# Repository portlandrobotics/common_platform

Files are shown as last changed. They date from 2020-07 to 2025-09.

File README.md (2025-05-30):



<!-- PROJECT SHIELDS -->
<!--
*** I'm using markdown "reference style" links for readability.
*** Reference links are enclosed in brackets [ ] instead of parentheses ( ).
*** See the bottom of this document for the declaration of the reference variables
*** for contributors-url, forks-url, etc. This is an optional, concise syntax you may use.
*** https://www.markdownguide.org/basic-syntax/#reference-style-links
-->
[][contributors-url]
[][forks-url]
[][stars-url]
[][issues-url]
[][license-url]

<!-- PROJECT LOGO -->
<br />
<div align="center">
  <a href="https://portlandrobotics.org/home.php?link_id=1">
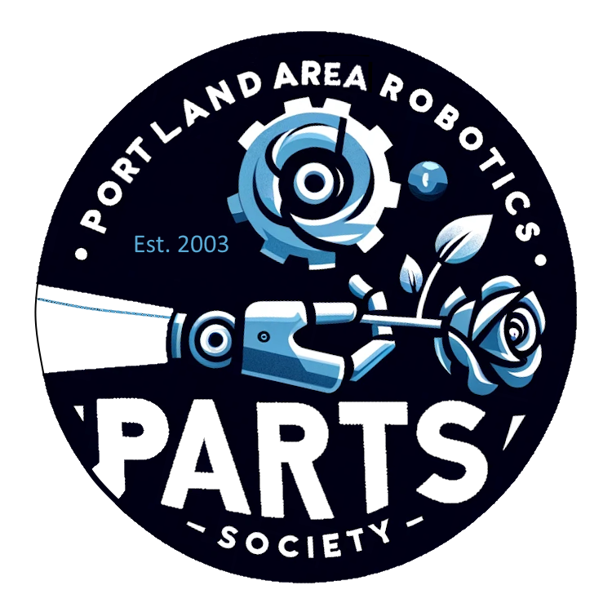
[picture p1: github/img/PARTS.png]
    
  </a>

  <h3 align="center">Portland Area Robotics Society -- Common Robotics Platform</h3>

  <p align="center">
    Build and master the Common Robotics Platform with Portland Area Robotics Society 
    <br />
    <a href="https://parts-common-platform.readthedocs.io/en/latest/"><strong>Explore the docs »</strong></a>
    <br />
    <br />
    <a href="https://github.com/portlandrobotics/common_platform">View Demo</a>  <!-- TODO We need to add a demo video here -->
    ·
    <a href="https://github.com/portlandrobotics/common_platform/issues">Report Bug</a>
    ·
    <a href="https://github.com/portlandrobotics/common_platform/issues">Request Feature</a>
  </p>
</div>

<!-- TABLE OF CONTENTS -->
<details>
  <summary>Table of Contents</summary>
  <ol>
    <li>
      <a href="#about-the-project">About The Project</a>
      <ul>
        <li><a href="#built-with">Built With</a></li>
      </ul>
    </li>
    <li>
      <a href="#getting-started">Getting Started</a>
      <ul>
        <li><a href="#prerequisites">Prerequisites</a></li>
        <li><a href="#installation">Installation</a></li>
      </ul>
    </li>
    <li><a href="#usage">Usage</a></li>
    <li><a href="#roadmap">Roadmap</a></li>
    <li><a href="#contributing">Contributing</a></li>
    <li><a href="#license">License</a></li>
    <li><a href="#contact">Contact</a></li>
    <li><a href="#acknowledgments">Acknowledgments</a></li>
  </ol>
</details>

<!-- ABOUT THE PROJECT -->
## About The Project

<br>
<p align="center">
  <a href="https://www.pololu.com/category/203/romi-chassis-kits">
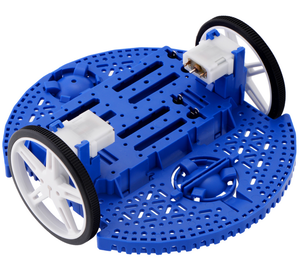
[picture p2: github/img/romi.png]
Romi Chassis
    
  </a>
</p>
<br>

Our project centers around the innovative construction and programming of a versatile robot using the robust Pololu Romi Chassis Kit as its foundation. At the heart of our design is a custom carrier PCB, which integrates seamlessly with the chassis, ensuring a compact and efficient layout. 

<br>
<p align="center">
  <a href="https://portlandrobotics.org/home.php?link_id=1">
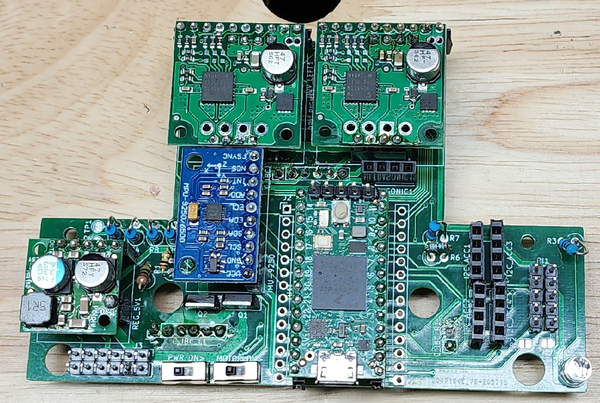
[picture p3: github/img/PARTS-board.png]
    
  </a>
<br>
<br>

Key components of our build include two TB9051FTG Single Brushed DC Motor Driver Carriers for precise motion control, and a Pololu 5V, 2.5A Step-Down Voltage Regulator D24V22F5 to ensure stable power supply. Navigation and orientation are handled by the sophisticated MPU-9250 9DOF Module, a nine-axis sensor that offers unparalleled accuracy in movement tracking. Additional hardware includes a set of Romi Encoders, a Romi Chassis Caster for stable maneuverability, and a powerful Teensy 4.0 microcontroller for robust processing capabilities. We've also incorporated an SPDT slide switch and two IRFU5505PBF transistors, supported by a suite of nine resistors of varying values to fine-tune our circuitry. 

<br>
<p align="center">
  <a href="https://www.pololu.com/category/203/romi-chassis-kits">
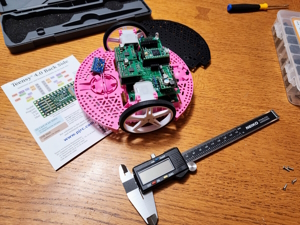
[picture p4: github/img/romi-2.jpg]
Romi Chassis
    
  </a>
</p>
<br>

Looking towards the future, our vision is to enhance this platform by integrating a Raspberry Pi, aiming to achieve autonomous functionality through the advanced capabilities of ROS2. This robot is not just a machine, but a gateway to exploring the vast possibilities of robotics, making it an ideal platform for enthusiasts and innovators alike in the Portland Area Robotics Society.

<p align="right">(<a href="#readme-top">back to top</a>)</p>

### Built With

* [][cpp-url]
* [][c-url]
* [][python-url]
* [][platformio-url]
* [][arduino-url]
* [][kicad-url]
* [][ros-url]

<p align="right">(<a href="#readme-top">back to top</a>)</p>

<!-- GETTING STARTED -->
## Getting Started

### Prerequisites

* All the required parts from the BOM on hand. [BOM](/BOM.csv)
* Windows/Mac/Linux PC
* Soldering supplies

### Installation

Welcome to the setup guide for the PARTS Common Robotics Platform. Follow these steps to prepare your hardware and software for an exciting journey into robotics!

#### 1. Solder Your PARTS CRP Board
Soldering the PARTS CRP board is the first crucial step. Follow the instructions carefully to ensure a successful setup.

- **Interactive BOM**: Utilize the [Interactive BOM](https://htmlpreview.github.io/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) for an easier soldering process.
- **Headers for Connectivity**: We recommend using headers for connections between boards. This makes disassembly possible if needed.
  - Use female (socket) headers on the bottom board.
  - Use male (pin) headers on the top board. These are typically included with all breakout boards.
- **MOSFET Orientation**: Ensure the correct orientation of the MOSFETs during soldering.
- **Resistor for Battery Voltage Divider**: Choose the resistor based on your battery choice:
  - Use a 2M ohm resistor (R1) for 6 AA batteries.
  - Opt for a 3M ohm resistor if using higher voltage batteries like 2 LiPo batteries.
  - Install a >100 pf capacitor across R2 to address voltage drop issues.
- **Teensy Board Modification**: For battery power, cut the trace on the Teensy board. Refer to the note "Cut to separate VIN from VUSB" on the [Teensy 4.0 Back Side](https://github.com/portlandrobotics/common_platform/blob/master/hardware/main_schematic.pdf) image.
- **Resistor Values**: The values of R4, R5, R8, R9 depend on your specific usage. For I2C, 4.7k is appropriate.
- **Schematic**: Refer to the [Main Schematic](https://github.com/portlandrobotics/common_platform/blob/master/hardware/main_schematic.pdf) for detailed understanding.

#### 2. Solder Accessories
Solder accessories like the Inertial Measurement Unit (IMU), ensuring proper orientation and connection.

#### 3. Assemble the Pololu Romi Chassis
The Pololu Romi Chassis forms the physical structure of your robot.

- Follow the [Romi Chassis Assembly Guide](https://www.pololu.com/docs/0J68/4) for detailed instructions on assembling the chassis.

#### 4. Install Arduino IDE
The Arduino Integrated Development Environment (IDE) is essential for programming your robot.

- Download and install the [Arduino IDE](https://www.arduino.cc/en/Main/Software) suitable for your operating system.

#### 5. Clone PARTS CRP Repository
Get the latest codebase for the PARTS CRP project by cloning the repository.

- Use Git to clone the repository or download it directly from the [PARTS CRP GitHub page](https://github.com/portlandrobotics/common_platform).

_For detailed instructions, please refer to the [Documentation](https://parts-common-platform.readthedocs.io/en/latest/)_

<p align="right">(<a href="#readme-top">back to top</a>)</p>

## Usage

This section provides practical examples of how to use the PARTS Common Robotics Platform effectively. We'll start with a basic test to ensure your setup is functioning correctly.

### Starting with the Basic Test

1. **Flash the Teensy 4.0 Board:**
   Begin by flashing the Teensy 4.0 board with the basic test code found in the repository at `/firmware/basic_test/basic_test.ino`. This initial test is crucial for validating your setup.

2. **Expected Behavior:**
   Upon successful flashing, the robot should exhibit a simple behavior pattern: moving forward, pausing, and then moving backward.

_For more examples, please refer to the [Documentation](https://parts-common-platform.readthedocs.io/en/latest/)_

<p align="right">(<a href="#readme-top">back to top</a>)</p>

<!-- ROADMAP -->
## Roadmap

- [ ] Build hardware library for common robotics platform
- [ ] Build manual for open robotics platform
     - [ ] SBC
     - [ ] Microcontroller
     - [ ] Software
     - [ ] Power
     - [ ] Motion
     - [ ] Communication
     - [ ] Sensors and cameras
     - [ ] Soldering
     - [ ] PCB design and ordering
- [ ] Create 3D model of platform for Gazebo and other sims
- [ ] ROS2 Setup
    - [ ] micro-ROS + ROS2 Humble
    - [ ] control
    - [ ] commuication
    - [ ] navigation
    - [ ] avoidance
 - [ ] Demo of system

See the [open issues](https://github.com/portlandrobotics/common_platform/issues) for a full list of proposed features (and known issues).

<p align="right">(<a href="#readme-top">back to top</a>)</p>

<!-- CONTRIBUTING -->
## Contributing

Contributions are what make the open source community such an amazing place to learn, inspire, and create. Any contributions you make are **greatly appreciated**.

If you have a suggestion that would make this better, please fork the repo and create a pull request. You can also simply open an issue with the tag "enhancement".
Don't forget to give the project a star! Thanks again!

1. Fork the Project
2. Create your Feature Branch (`git checkout -b feature/AmazingFeature`)
3. Commit your Changes (`git commit -m 'Add some AmazingFeature'`)
4. Push to the Branch (`git push origin feature/AmazingFeature`)
5. Open a Pull Request

<p align="right">(<a href="#readme-top">back to top</a>)</p>

<!-- LICENSE -->
## License

Distributed under the MIT License and the Solderpad Hardware License v2.1. See [LICENSE.txt][license-url] for more information.

<p align="right">(<a href="#readme-top">back to top</a>)</p>

<!-- MARKDOWN LINKS & IMAGES -->
<!-- https://www.markdownguide.org/basic-syntax/#reference-style-links -->
[contributors-shield]: https://img.shields.io/github/contributors/portlandrobotics/common_platform.svg?style=for-the-badge
[contributors-url]: https://github.com/portlandrobotics/common_platform/graphs/contributors
[forks-shield]: https://img.shields.io/github/forks/portlandrobotics/common_platform.svg?style=for-the-badge
[forks-url]: https://github.com/portlandrobotics/common_platform/network/members
[stars-shield]: https://img.shields.io/github/stars/portlandrobotics/common_platform.svg?style=for-the-badge
[stars-url]: https://github.com/portlandrobotics/common_platform/stargazers
[issues-shield]: https://img.shields.io/github/issues/portlandrobotics/common_platform.svg?style=for-the-badge
[issues-url]: https://github.com/portlandrobotics/common_platform/issues
[license-shield]: https://img.shields.io/badge/license-mit_%26_solderpad-brightgreen?style=for-the-badge
[license-url]: https://github.com/portlandrobotics/common_platform/blob/master/LICENSE.txt
[arduino-ide]: https://img.shields.io/badge/Arduino_IDE-00979D?style=for-the-badge&logo=arduino&logoColor=white
[arduino-url]: https://www.arduino.cc/en/software
[cpp]: https://img.shields.io/badge/C%2B%2B-00599C?style=for-the-badge&logo=c%2B%2B&logoColor=white
[cpp-url]: https://en.wikipedia.org/wiki/C%2B%2B
[c]: https://img.shields.io/badge/C-00599C?style=for-the-badge&logo=c&logoColor=white
[c-url]: https://en.wikipedia.org/wiki/C_(programming_language)
[python]: https://img.shields.io/badge/Python-3776AB?style=for-the-badge&logo=python&logoColor=white
[python-url]: https://www.python.org/
[platformio]: https://img.shields.io/badge/PlatformIO-F5822A.svg?style=for-the-badge&logo=PlatformIO&logoColor=white
[platformio-url]: https://platformio.org/
[kicad]: https://img.shields.io/badge/KiCad-314CB0.svg?style=for-the-badge&logo=KiCad&logoColor=white
[kicad-url]: https://www.kicad.org/
[ros]: https://img.shields.io/badge/ROS-22314E.svg?style=for-the-badge&logo=ROS&logoColor=white
[ros-url]:https://www.ros.org/

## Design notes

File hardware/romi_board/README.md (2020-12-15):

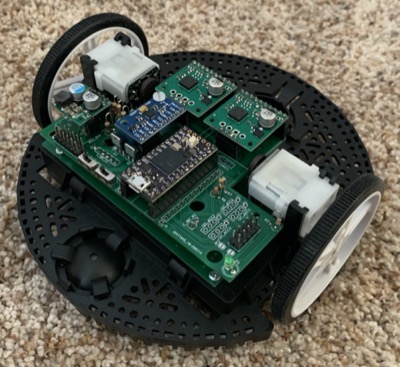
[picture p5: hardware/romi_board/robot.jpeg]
robot


## Assembly Notes

- In general, follow the instructions in the Romi chassis assembly [guide](https://www.pololu.com/docs/0J68/4).  Note that wheel encoders should be installed as shown in those instructions and will plug into the bottom board.
- The [interactive BOM](https://htmlpreview.github.io/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) is helpful while soldering components onto the board.
- We recommend using headers between the boards so that disassembly is possible.  Use female (socket) header on the bottom board and male (pin) headers on top board.  Pin headers come with all of the breakout boards.  
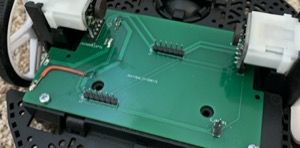
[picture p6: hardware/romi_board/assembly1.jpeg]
assembly1
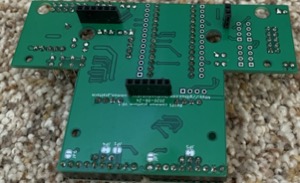
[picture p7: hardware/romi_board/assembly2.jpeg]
assembly2
 
- Use the top board to guide breakout board header soldering.  Insert the pin headers into the appropriate positions on the top board and then add the breakout boards onto the pins and solder them to the breakout boards. 
We recommend using socket headers on the top board for all of the breakout board positions so that they can be plugged in- Brace the IMU with extra header or cardboard or some other means.  Shown below is a 3D printed block but anything of the appropriate size will do.  
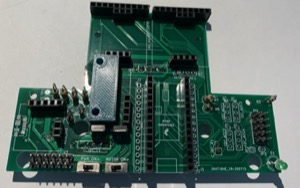
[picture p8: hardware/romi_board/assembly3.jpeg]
assembly3

- The three pin header on the motor driver is not needed and can be left without header pins.
- Pay attention to the orientation of the MOSFETs
- Use 2M ohm resistor for the battery voltage resistor divider (R1) if you use the 6 AA batteries.  If you use higher voltage batteries (2 LiPo batteries for example) then use a 3M ohm resistor.
- Cut trace on teensy for battery power.  See the note "Cut to separate VIN from VUSB" on the "Teensy 4.0 Back Side" image on this [page](https://www.pjrc.com/store/teensy40.html).
- If you want to mount a Raspberry Pi on the robot, this is how to use standoffs to do so:  
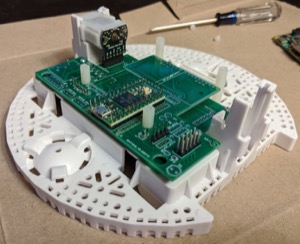
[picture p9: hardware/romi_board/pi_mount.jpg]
pi


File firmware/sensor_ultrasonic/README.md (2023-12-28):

# Ultrasonic Sensor Test

## Overview
This project involves using an Arduino/Teensy to test an HC-SR04 ultrasonic sensor. The `ultrasonic_test.ino` sketch measures the distance to an object and prints the result to the Serial Monitor.

## Requirements
- Arduino Compatible Device (Teensy, Uno, Mega, or similar)
- HC-SR04 Ultrasonic Sensor
- Jumper Wires

## Wiring
Connect the ultrasonic sensor to the Teensy 4.0:
- VCC to 5V
- GND to GND
- TRIG to Pin 9
- ECHO to Pin 15
  
OR

- Hook sensor to ULTRASONIC1 on Common Robotics Platform Main Board. Pin 1 VCC, Pin 2 Trigger, Pin 3 Echo, Pin 4 Ground. Looking at the common robotics platform board from the top, find the label "ULTRASONIC1" - Pin 1 is toward the U on ULTRASONIC1.
  - Ensure R6 3.3k and R7 4.6k resistors are installed so we don't burn out the teensy.

## Installation
1. Connect the Teensy/Arduino to your computer.
2. Open the `ultrasonic_test.ino` sketch in the Arduino IDE.
3. Upload the sketch to your Arduino board.

## Usage
After uploading the sketch, open the Serial Monitor in the Arduino IDE. You should see distance measurements displayed in centimeters, updated approximately every half second.

## Troubleshooting
- Ensure all connections are secure.
- Verify that the correct COM port is selected in the Arduino IDE.
- Ensure that your Arduino board is compatible with the sketch.

For more information or assistance, refer to the documentation of the HC-SR04 ultrasonic sensor and the Teensy/Arduino board being used.

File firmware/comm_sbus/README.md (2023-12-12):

# SBUS Test Readme

## Overview

The SBUS (Serial Bus) protocol is a digital communication protocol used in remote control equipment, particularly for communicating with RC (radio controlled) servos. It is favored for its efficiency and capability to handle multiple channels over a single wire. This README guides you through integrating SBUS control with our PARTS Robot using the [bolderflight/sbus](https://github.com/bolderflight/sbus) library.

Our project leverages the SBUS protocol to enable precise and responsive control over the PARTS Robot. By using SBUS, we can efficiently manage multiple control signals, such as steering and throttle, through a single digital connection. This approach simplifies wiring, increases reliability, and enhances the overall responsiveness of the robot. The SBUS library by Bolder Flight Systems provides a convenient and robust way to implement SBUS communication in our system, especially when interfaced with a Teensy microcontroller.

## Prerequisites
- A working installation of Teensy microcontroller.
- Basic understanding of SBUS communication protocol.
- A compatible SBUS transmitter and receiver.

## Installation and Setup

1. **Library Installation**: Download and install the sbus library from [bolderflight/sbus](https://github.com/bolderflight/sbus).

2. **Hardware Connection**: 
   - Connect the SBUS out on your receiver to an open Serial RX port on your Teensy. 
   - In this example, RX4 (Serial4) on the teansy, which is also connected to I2C2 on the common platform board, is used. Connect the yellow wire from your reciever here. 
   - Connect the red wire to 5V and the black wire to ground.  
   - Ensure that R8 on the common platform board is disconnected.

3. **Firmware Upload**:
   - Flash your Teensy with the firmware. You can find the firmware file `sbus_test.ino` in this repository. Click [here](./sbus_test.ino) to view or download it.

4. **Transmitter Setup**:
   - Configure your transmitter to output on Channels 1 and 2. Standard AETR configuration means the right stick will control the robot.
   - Ensure your transmitter is bound to your receiver.

5. **Receiver Configuration**:
   - Make sure the receiver is in SBUS mode and not CPPM.

6. **Power and Test**:
   - Power up the system and test the functionality.
   - Data is logged to USB serial for monitoring.

## Important Parameters

- **Serial Port Configuration**:
  To change the serial port, modify the following line in your code:

  ```cpp 
  bfs::SbusRx sbus_rx(&Serial4, true); // Setup SBUS using Serial4 (RX4), using a standard SBUS inverted signal
  ```

- **Channel Configuration**:
  To change the channels you are monitoring:

  ```cpp
  int linear = map(data.ch[1], 172, 1810, -MAX_PWM, MAX_PWM);  // Channel 2 for linear speed
  int angular = map(data.ch[0], 172, 1810, -MAX_PWM, MAX_PWM); // Channel 1 for angular speed
  ```

- **Maximum Speed Setting**:
  To change the maximum speed:

  ```cpp
  const int MAX_PWM = 200;        // Maximum PWM value for motor speed 0-255
  ```

## Tested Hardware

- Radiomaster Zorro jp4in1
- FRSky R-XSR Sbus Receiver

## Contributing

For any suggestions or contributions, please create an issue or pull request on the GitHub repository.

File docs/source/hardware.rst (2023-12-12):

.. _hardware:

Hardware Guide
==============

This document provides a comprehensive overview of the hardware components of the PARTS- Common Robotics Platform. It covers the details of the Romi Chassis, the custom carrier board, and any additional hardware used in the project.

Introduction to the Hardware
-----------------------------

Start with a brief introduction to the hardware components of your Romi Chassis Robot. Explain the significance of each component and how they collectively contribute to the functionality of the robot.

- **Romi Chassis**: Provide a description of the Romi Chassis, its specifications, and features.
- **Custom Carrier Board**: Elaborate on the custom carrier board, its purpose, and how it enhances or modifies the capabilities of the Romi Chassis.

List of Hardware Components
---------------------------

Create a detailed list of all the hardware components used in the project, including:

- **Main Components**: Such as motors, sensors, battery packs, etc.
- **Additional Components**: Any additional hardware that is part of the project, like external sensors, communication modules, etc.
- **Custom Parts**: Detail any custom-made parts or modifications done to existing components.

Assembling the Romi Chassis
---------------------------

Provide a step-by-step guide on assembling the Romi Chassis. Include:

- **Assembly Instructions**: Detailed instructions on how to assemble the Romi Chassis.
- **Diagrams or Images**: Visual aids can be highly beneficial here. Make sure to include clear, annotated images or diagrams.

Integrating the Custom Carrier Board
-------------------------------------

Detail the process of integrating the custom carrier board with the Romi Chassis. This section can include:

- **Installation Steps**: Step-by-step instructions for installing the carrier board.
- **Wiring Diagrams**: Provide detailed wiring diagrams showing how the carrier board is connected to the Romi Chassis and other components.
- **Configuration Settings**: If any configuration changes are needed for the carrier board to function correctly with the Romi Chassis.

Safety Precautions
------------------

Discuss the safety measures that should be taken when assembling and handling the robot's hardware.

- **Handling Electronics**: Tips on safely handling electronic components.
- **Battery Safety**: Guidelines for using and storing batteries.

Troubleshooting Common Hardware Issues
--------------------------------------

Provide solutions to some common hardware-related problems that users might encounter.

- **Symptom-Based Troubleshooting Guide**: List common symptoms and their potential solutions.
- **Maintenance Tips**: Advice on regular maintenance practices to keep the hardware in good working condition.

Conclusion
----------

Conclude the hardware overview by summarizing the key points. Encourage readers to proceed to the software documentation for information on how to operate the assembled hardware.

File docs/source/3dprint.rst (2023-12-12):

.. _3d_printed_parts:

3D Printed Parts
================

This document provides information about the 3D printed parts used in the [Project Name or PARTS Romi Chassis Robot, as applicable]. It covers the list of parts, printing instructions, and assembly guidelines.

List of 3D Printed Parts
------------------------

Introduce the list of 3D printed parts required for the project. For each part, include its name, purpose, and any other relevant details.

- **Part Name 1**: Brief description of Part 1.
- **Part Name 2**: Brief description of Part 2.
- [Continue as needed]

Printing Instructions
---------------------

Offer guidelines for printing the 3D parts.

- **Recommended Printer Settings**: Discuss settings like layer height, infill, print speed, and material type.
- **File Formats and Sources**: Provide information on where to download the 3D models (e.g., STL files) and any necessary file preparation.
- **Post-Processing Tips**: Include any post-processing steps needed after printing (like sanding, painting, etc.).

Assembly Guidelines
-------------------

Provide instructions on how to incorporate the 3D printed parts into your project.

- **Step-by-Step Assembly**: Guide users through the steps of assembling the printed parts into the project.
- **Integration with Other Components**: Explain how these parts integrate with other non-printed components.

Troubleshooting and Tips
------------------------

Share tips for troubleshooting common issues related to 3D printing or assembling these parts.

- **Common Printing Issues**: Address typical 3D printing problems like warping, stringing, or layer separation.
- **Assembly Challenges**: Offer solutions for common assembly challenges.

Conclusion
----------

Wrap up the document with any concluding remarks or pointers to further resources.

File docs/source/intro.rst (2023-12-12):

.. _intro:

Introduction
============

Welcome to the documentation for the PARTS- Common Robotics Platform! This document serves as an introduction to the Romi Chassis, a versatile and compact robotic platform, and outlines how it is used and customized in our PARTS project.

What is the Romi Chassis?
-------------------------

The Romi Chassis is a [brief description of the Romi Chassis, its features, and its typical applications].

About This Project
------------------

This section should provide an overview of your specific project. Discuss what the PARTS- Common Robotics Platform is, its objectives, and what makes it unique or different from standard implementations. 

- **Project Goals**: Outline the goals or problems that this project aims to address.
- **Custom Features**: Highlight any custom features or modifications made to the standard Romi Chassis in this project.

Getting Started
---------------

Here, guide the reader on how to begin with the PARTS- Common Robotics Platform.

- **Prerequisites**: List any prerequisites, such as hardware components, software requirements, or knowledge prerequisites.
- **Initial Setup**: Briefly describe the initial setup steps or refer the reader to a section in the documentation where the setup is detailed.

Project Components
------------------

Provide an overview of the different components of the project, such as:

- **Hardware Components**: List the hardware components, including the Romi Chassis and any additional modules or sensors used.
- **Software and Firmware**: Mention the software, firmware, or any special programming environments used in the project.

How to Use This Documentation
-----------------------------

Guide the reader on how to navigate and use this documentation effectively.

- **Navigation Tips**: Explain how to navigate through the documentation, referring to the table of contents or any search functionality.
- **Conventions Used**: If there are any special notations, conventions, or symbols used in the documentation, explain them here.

Contact and Support
-------------------

Provide information on how readers can get support, ask questions, or contribute to the project.

- **Support Channels**: List available support channels like email, forums, or social media links.
- **Contributing**: If open to contributions, explain how others can contribute to the project.

Conclusion
----------

Conclude the introduction with a brief summary and encourage the reader to explore the rest of the documentation.

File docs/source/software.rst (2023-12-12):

.. _software:

Software Guide
==============

This section of the documentation covers the software aspects of the PARTS- Common Robotics Platform. It includes information on firmware installation, software setup, programming instructions, and troubleshooting.

Introduction to the Software Setup
-----------------------------------

Begin with an overview of the software component of the project. Explain the significance of the software in operating and controlling the Romi Chassis Robot.

- **Software Overview**: Briefly describe the software environment and its role in the functionality of the robot.
- **Firmware and Software Requirements**: List the firmware and software needed for the project, including versions and where to download them.

Firmware Installation
---------------------

Detail the process of installing or flashing the firmware onto the custom carrier board or any other programmable components.

- **Firmware Installation Steps**: Provide step-by-step instructions for installing the firmware.
- **Troubleshooting Firmware Installation**: Offer solutions to common issues encountered during firmware installation.

Setting Up the Development Environment
--------------------------------------

Guide users through setting up their development environment for programming the robot.

- **Required Software**: List all the software tools and IDEs required.
- **Installation Guide**: Step-by-step installation instructions for the software tools.
- **Configuration Settings**: Any necessary configuration settings or tips to get the development environment ready.

Programming the Romi Chassis Robot
----------------------------------

Provide information on how to program the robot, including basic programming tutorials and examples.

- **Basic Programming Tutorial**: Start with simple examples to control basic functions of the Romi Chassis.
- **Advanced Features**: If applicable, provide guidance on more advanced programming features or custom functionalities.
- **Code Samples**: Include sample code snippets or link to a repository where users can find example code.

Integrating Software with Hardware
----------------------------------

Explain how the software interacts with the hardware components of the robot.

- **Software-Hardware Interface**: Describe how the software sends commands to and receives data from the hardware.
- **Debugging Tips**: Offer tips on debugging software-hardware integration issues.

Troubleshooting Common Software Issues
--------------------------------------

Provide a troubleshooting guide for common software-related problems.

- **Common Issues and Solutions**: List frequently encountered software issues and their solutions.
- **Support Resources**: Mention where users can find additional help, such as forums, community groups, or support channels.

Conclusion
----------

Conclude the software guide by summarizing the key points and encouraging users to experiment and explore further functionalities.

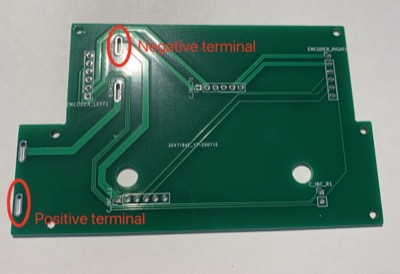
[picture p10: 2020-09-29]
hardware/romi_board/terminals.jpeg

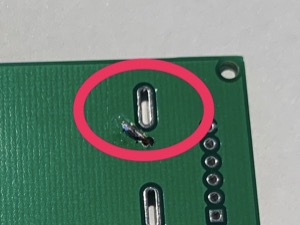
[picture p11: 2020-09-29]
hardware/romi_board/rework3.jpeg

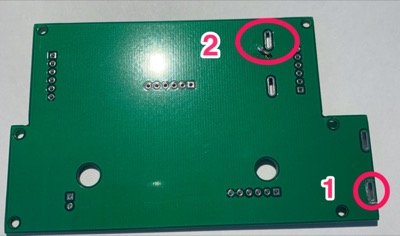
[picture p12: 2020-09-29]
hardware/romi_board/rework1.jpeg

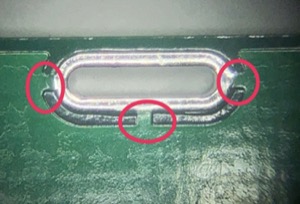
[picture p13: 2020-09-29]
hardware/romi_board/rework2.jpeg

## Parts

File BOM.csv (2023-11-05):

Name | Quantity | Description | URL | Price (each)
Motor Driver | 2 | TB9051FTG Single Brushed DC Motor Driver Carrier | https://www.pololu.com/product/2997/resources | $11.95
Voltage Regulator | 1 | Pololu 5V, 2.5A Step-Down Voltage Regulator D24V22F5 | https://www.pololu.com/product/2858/resources | $8.95
IMU | 1 | MPU-9250 9DOF Module Nine-axis | https://www.amazon.com/HiLetgo-Gyroscope-Acceleration-Accelerator-Magnetometer/dp/B01I1J0Z7Y | $14.99
Chassis | 1 | Romi Chasis Kit | https://www.pololu.com/category/203/romi-chassis-kits | $39.95
Wheel Encoders | 1 | Romi Encoder (pair) | https://www.pololu.com/product/3542 | $9.95
Caster | 1 | Romi Chasis Caster | https://www.pololu.com/product/3530 | $3.95
Processor | 1 | Teensy 4.0 | https://www.pjrc.com/store/teensy40.html | $23.80
Switch | 2 | SPDT slide switch | https://www.pololu.com/product/1408 | $1.69
MOSFET | 2 | MOSFET | https://www.digikey.com/product-detail/en/infineon-technologies/IRFU5505PBF/IRFU5505PBF-ND/812417 | 0.86
Chassis | 1 | Alternate chassis | https://www.sparkfun.com/products/16405 | 14.95

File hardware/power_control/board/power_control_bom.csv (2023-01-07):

Reference | Quantity | Value | Footprint | Digikey Part | MFG Part | Description | Datasheet
C1 C3 C4 | 3 | 2.2u | Capacitor_SMD:C_0603_1608Metric_Pad1.08x0.95mm_HandSolder |  |  |  | ~
C2 C5 | 2 | 100n | Capacitor_SMD:C_0603_1608Metric_Pad1.08x0.95mm_HandSolder |  |  |  | ~
J1 J2 | 2 | Conn_01x03 | Connector_PinHeader_2.54mm:PinHeader_1x03_P2.54mm_Vertical |  |  |  | ~
J3 | 1 | Conn_01x04 | Connector_PinHeader_2.54mm:PinHeader_1x04_P2.54mm_Vertical |  |  |  | ~
J4 | 1 | Conn_01x06 | Connector_PinHeader_2.54mm:PinHeader_1x06_P2.54mm_Vertical |  |  |  | ~
J5 | 1 | Conn_01x02 | Connector_PinHeader_2.54mm:PinHeader_1x02_P2.54mm_Vertical |  |  |  | ~
J6 | 1 |  | Package_TO_SOT_SMD:SOT-363_SC-70-6_Handsoldering | 1727-2733-1-ND | NX138BKSX | MOSFET 2 N-CH 60V 210MA 6TSSOP | ~
R1 | 1 | 330k | Resistor_SMD:R_0603_1608Metric_Pad0.98x0.95mm_HandSolder |  |  |  | ~
R2 | 1 | 1M | Resistor_SMD:R_0603_1608Metric_Pad0.98x0.95mm_HandSolder |  |  |  | ~
R3 | 1 | 4.7k | Resistor_SMD:R_0603_1608Metric_Pad0.98x0.95mm_HandSolder |  |  |  | ~
R5 | 1 | 1k | Resistor_SMD:R_0603_1608Metric_Pad0.98x0.95mm_HandSolder |  |  |  | ~
R7 R8 R9 R10 R11 | 5 | 10k | Resistor_SMD:R_0603_1608Metric_Pad0.98x0.95mm_HandSolder |  |  |  | ~
SW1 | 1 | SW_Push | Button_Switch_SMD:SW_SPST_TL3305A | EG5350CT-ND | TL3305AF160QG | SWITCH TACTILE SPST-NO 50MA 12V | ~
U1 | 1 | MCP1703A-5002_SOT23 | Package_TO_SOT_SMD:SOT-23 | MCP1792T-3302H/CBCT-ND | MCP1792T-3302H/CB | IC REG LIN 3.3V 100MA SOT23A-3 | http://ww1.microchip.com/downloads/en/DeviceDoc/20005122B.pdf
U2 | 1 | ATtiny1604-SS | Package_SO:SOIC-14_3.9x8.7mm_P1.27mm | ATTINY1604-SSNRCT-ND | ATTINY1604-SSNR | IC MCU 8BIT 16KB FLASH 14SOIC | http://ww1.microchip.com/downloads/en/DeviceDoc/ATtiny804_1604-Data-Sheet-40002028A.pdf

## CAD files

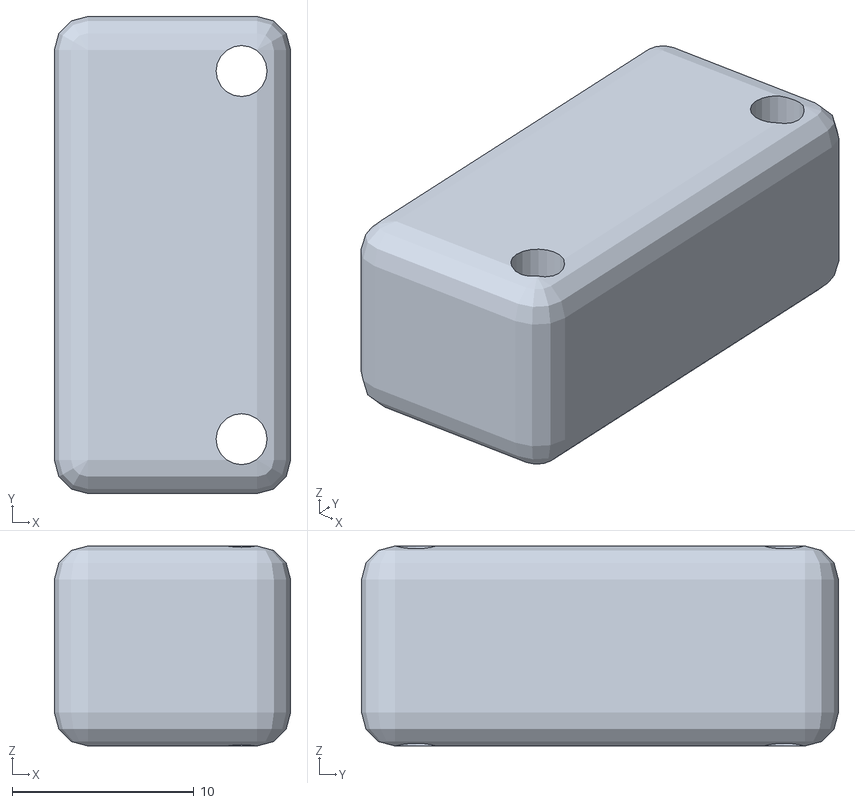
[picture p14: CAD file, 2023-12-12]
3dprint/Common_Robotics_IMU_Support.stl
13.0 x 26.2 x 11.0

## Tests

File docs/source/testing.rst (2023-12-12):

.. _testing:

Testing and Validation
======================

This section of the documentation focuses on testing and validating the PARTS- Common Robotics Platform. It includes guidelines on how to conduct tests to ensure the robot is functioning as expected, both in terms of hardware and software.

Introduction to Testing
-----------------------

Start with an overview of the importance of testing in the development and use of the Romi Chassis Robot.

- **Purpose of Testing**: Explain why testing is crucial for verifying the functionality and safety of the robot.
- **Testing Scope**: Outline what aspects of the robot will be covered in the testing procedures (e.g., hardware integrity, software functionality, overall system performance).

Hardware Testing
----------------

Provide instructions for testing the hardware components of the robot.

- **Visual Inspection**: Guidelines for a preliminary check of the hardware for any visible issues.
- **Connectivity Tests**: Steps to ensure all components are properly connected and communicating.
- **Motor and Sensor Tests**: Procedures for testing the motors, sensors, and other hardware components to ensure they are functioning correctly.

Software Testing
----------------

Outline the process for testing the software aspects of the robot.

- **Firmware Verification**: How to verify that the firmware is correctly installed and operating.
- **Functionality Tests**: Specific tests to run to ensure the software is performing as expected, controlling the hardware effectively.
- **Debugging Tips**: Provide guidance on how to troubleshoot common software issues.

Integration Testing
-------------------

Discuss how to test the integration of the hardware and software components.

- **System Tests**: Procedures for testing the robot as a whole system, ensuring hardware and software components work together seamlessly.
- **Performance Tests**: Guidance on how to assess the performance of the robot, such as response times, accuracy of movements, and endurance.

Safety Testing
--------------

Emphasize the importance of safety in testing and provide guidelines for safe testing practices.

- **Safety Precautions**: Outline necessary safety measures to take while testing the robot.
- **Emergency Procedures**: Instructions on what to do in case of a malfunction or emergency situation during testing.

Troubleshooting Common Issues
-----------------------------

Offer solutions and advice for common issues that might arise during testing.

- **Diagnostic Tips**: Methods for diagnosing problems during testing.
- **Problem-Solving Strategies**: Suggestions for resolving common testing issues.

Conclusion
----------

Conclude the testing documentation by summarizing the key points. Encourage users to thoroughly test their Romi Chassis Robots and report any issues or feedback for continuous improvement.

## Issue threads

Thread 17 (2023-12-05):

Scope and Requirements for a Common Robotics Platform Library

jhiggason, 2023-12-05:
### 1. Define the Scope and Requirements

#### A. Functionalities and Features
1. **Sensor Integration**
   - List all types of sensors you plan to use (IMUs, Ultra-Sonic, lidar, depth camera, magnetometer, barometer/temp,  RGB Cameras, GPS)
   - Define the data format and frequency of readings.

2. **Actuator Control**
   - Detail the types of actuators (e.g., motors, servos) and their control requirements.
   - Specify control mechanisms (e.g., PWM, digital signals).

3. **Communication Protocols**
   - Identify the communication protocols required (I2C, SPI, UART, etc.).
   - Outline the data transfer rates and protocol-specific features needed.

4. **Power Management**
   - Define how the Teensy will manage power for sensors and actuators.
   - Include any necessary power regulation or distribution features.

5. **Error Handling and Diagnostics**
   - Plan for error detection and handling mechanisms.
   - Plan for a display of some sort
   - Consider diagnostic tools or functions for troubleshooting.

#### B. Hardware Interface
1. **Pinout Configuration**
   - Map out the Teensy pins to be used for different functions.

2. **Physical Integration**
   - Outline how the Teensy  physically connects to the main board.
   - Plan for any necessary connectors or wiring schemes.

#### C. Compatibility and Scalability
1. **microROS Integration**
   - Define how the library will support microROS.
   - Plan for compatibility with ROS 2 on the Raspberry Pi or other SBC.

2. **Scalability**
   - Ensure the library can be easily expanded for additional sensors, actuators, or features.
   - Consider modular design to facilitate future enhancements.

#### D. Performance Requirements
1. **Processing Speed and Efficiency**
   - Specify the required response times and processing speeds.
   - Consider the computational load and memory usage.

2. **Reliability and Robustness**
   - Define reliability requirements, especially for critical functions.
   - Plan for robust operation under various conditions.

#### E. Future-Proofing
1. **Updates and Maintenance**
   - Outline a strategy for updating and maintaining the library.
   - Consider backward compatibility with future Teensy versions.

2. **Adaptability to New Technologies**
   - Keep provisions for integrating new sensors or communication protocols that may emerge.

#### F. Documentation and User Support
1. **Documentation Standards**
   - Plan for comprehensive documentation of the library.
   - Include code comments, API documentation, and user guides.

2. **User Support**
   - Consider how users will get support, possibly through forums, FAQs, or direct contact.

jhiggason, 2023-12-05:
For A.1. We need to decide which sensors the platform will officially support.  MPU-9250, encoders, and Ultra-sonic sensors seem like a no brainer.

### Sensor Categories for Flying and Ground Robots

#### 1. **Navigation Sensors**
   - **GPS Modules**: For outdoor positioning and navigation.
   - **IMU (Inertial Measurement Units)**: Combines accelerometers, gyroscopes, and sometimes magnetometers for orientation and movement detection.
   - **Compasses**: For directional orientation, especially important in environments where GPS is unreliable.

#### 2. **Environmental Sensors**
   - **Barometric Pressure Sensors**: For altitude estimation in flying robots.
   - **Temperature and Humidity Sensors**: For monitoring environmental conditions.
   - **Gas Sensors**: To detect various gases, useful in pollution monitoring or hazardous environment exploration.

#### 3. **Proximity and Distance Sensors**
   - **Ultrasonic Sensors**: For obstacle detection and range finding.
   - **LIDAR (Light Detection and Ranging)**: For high-precision distance measurement and mapping.
   - **Infrared Sensors**: For short-range object detection and line following.

#### 4. **Vision and Imaging Sensors**
   - **Cameras**: Standard visual cameras for image capture and video streaming.
   - **Thermal Cameras**: For heat signature detection, useful in search and rescue.
   - **3D Cameras/Depth Sensors**: For spatial mapping and object recognition.

#### 5. **Motion and Speed Sensors**
   - **Encoders**: For measuring rotation or linear motion, often used in wheels or joints.
   - **Gyroscopes**: For measuring or maintaining orientation and angular velocity.
   - **Accelerometers**: For measuring acceleration forces.

#### 6. **Tactile Sensors**
   - **Touch Sensors**: For detecting physical contact or collision.
   - **Force Sensors**: For measuring the force exerted on a surface or object.

#### 7. **Acoustic Sensors**
   - **Microphones**: For sound detection, useful in voice-controlled applications or environmental monitoring.
   - **Sonar**: Primarily used in underwater robotics for mapping and navigation.

#### 8. **Wireless Communication Sensors**
   - **RFID Readers**: For identification and tracking applications.
   - **Bluetooth Modules**: For short-range wireless communication.
   - **Wi-Fi Modules**: For internet connectivity and remote control.

#### 9. **Specialized Sensors**
   - **Biological and Chemical Sensors**: For detecting specific biological or chemical substances.
   - **Radiation Detectors**: For measuring ionizing radiation, useful in nuclear facility inspection.

#### 10. **Power and Battery Sensors**
   - **Voltage and Current Sensors**: For monitoring the power usage and battery life.

jhiggason, 2023-12-16:
I'm going to close this for the time being until I have time to back over this stuff and decide what really important.

Closed 2023-12-16.

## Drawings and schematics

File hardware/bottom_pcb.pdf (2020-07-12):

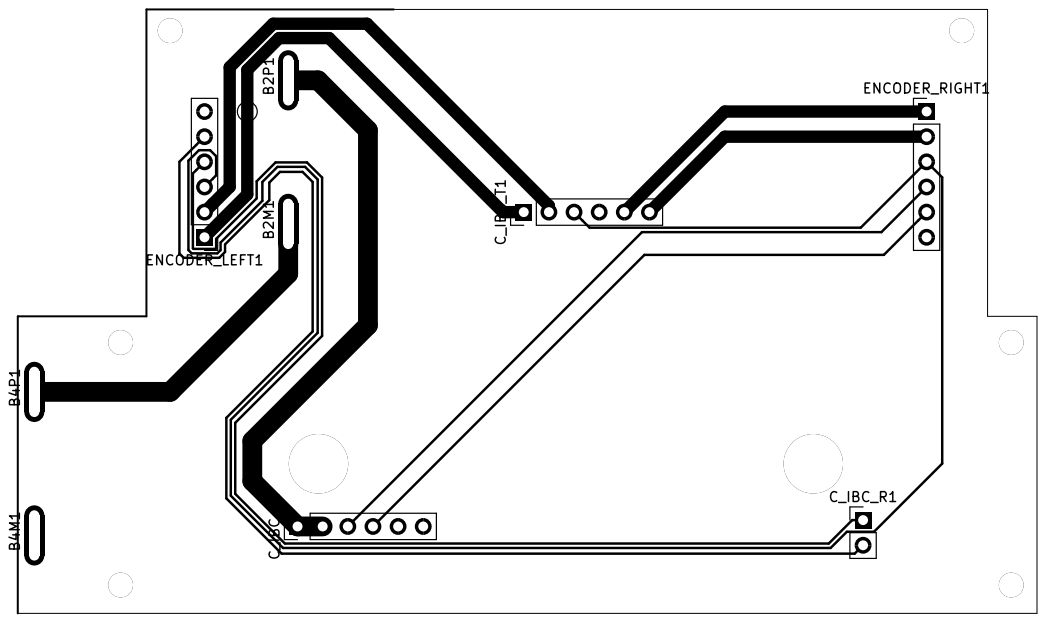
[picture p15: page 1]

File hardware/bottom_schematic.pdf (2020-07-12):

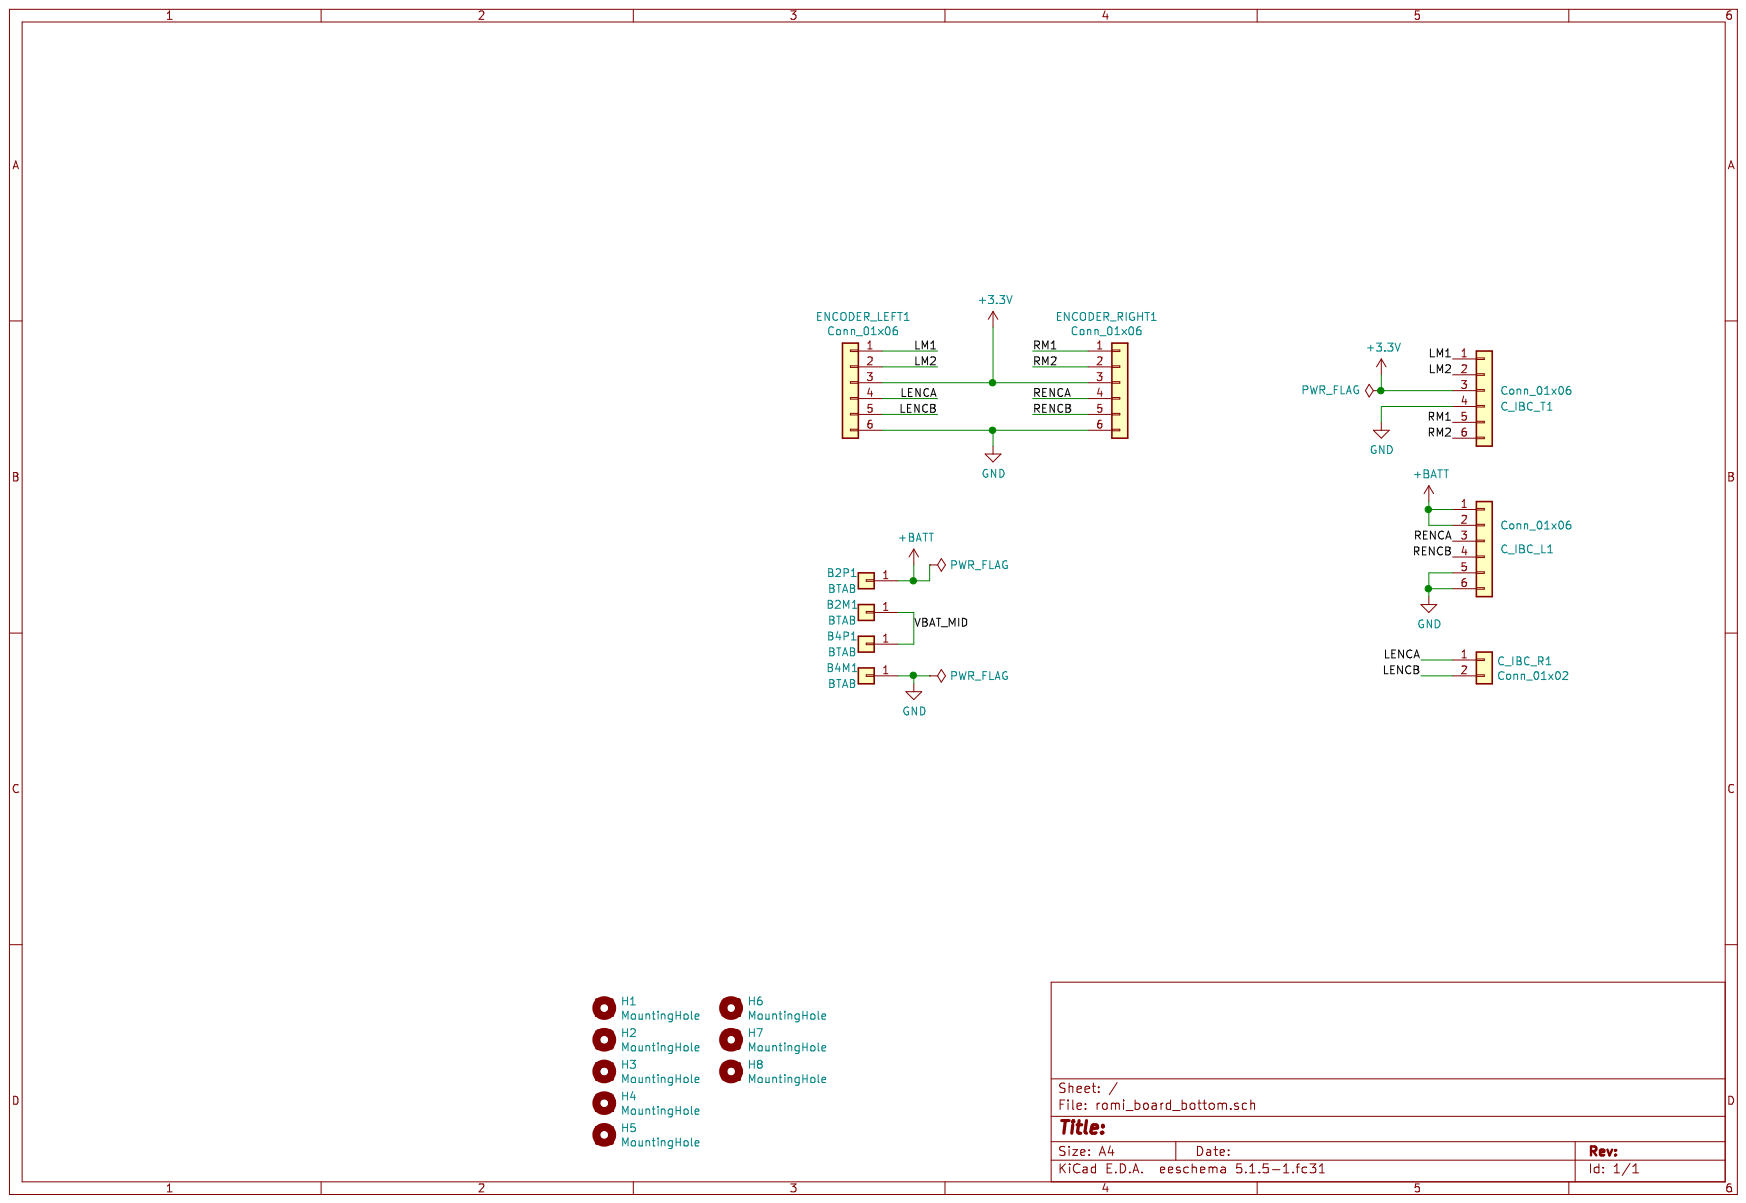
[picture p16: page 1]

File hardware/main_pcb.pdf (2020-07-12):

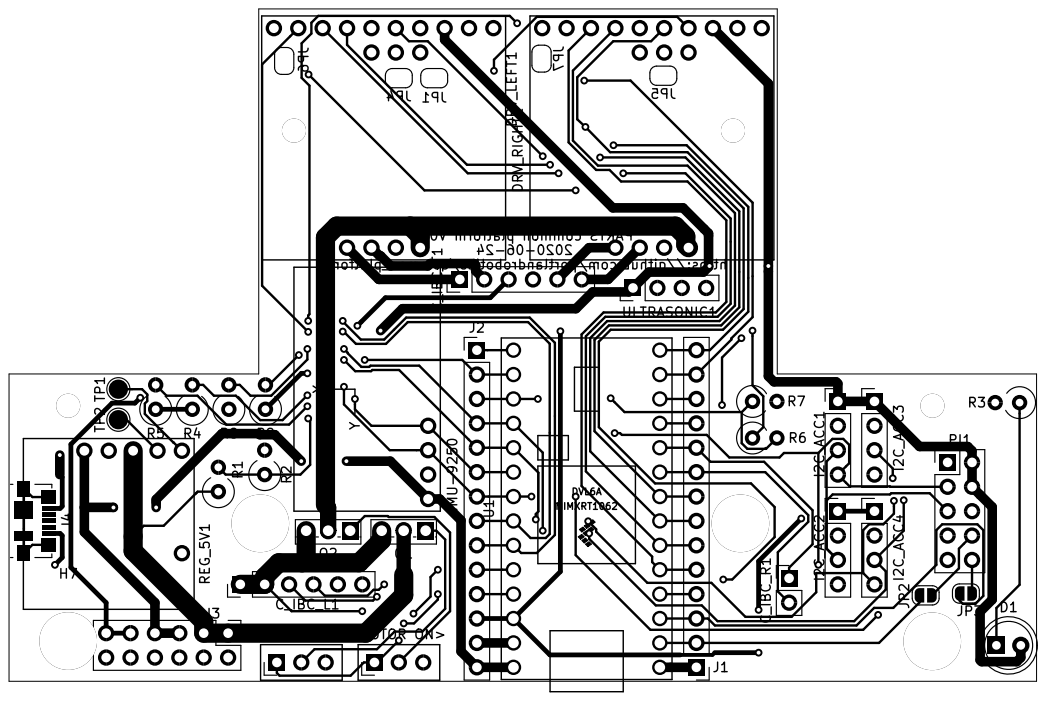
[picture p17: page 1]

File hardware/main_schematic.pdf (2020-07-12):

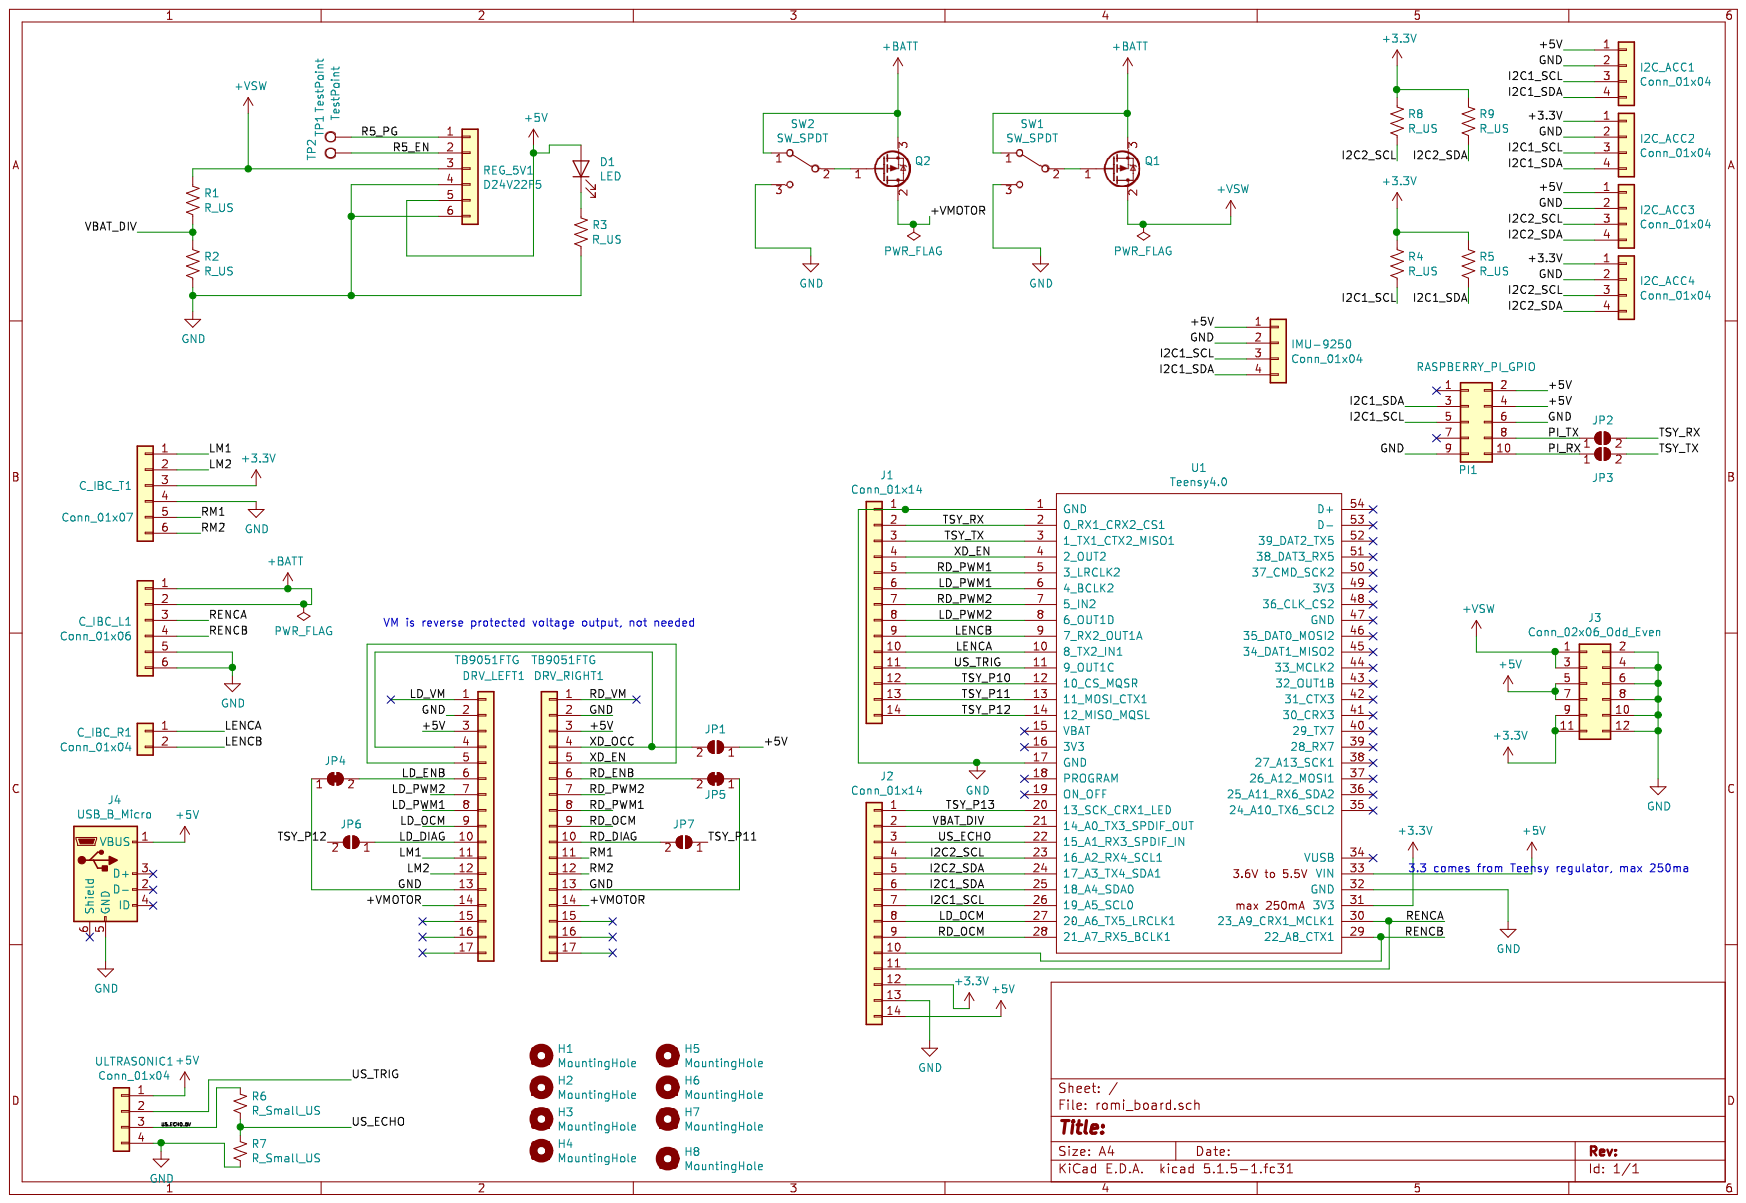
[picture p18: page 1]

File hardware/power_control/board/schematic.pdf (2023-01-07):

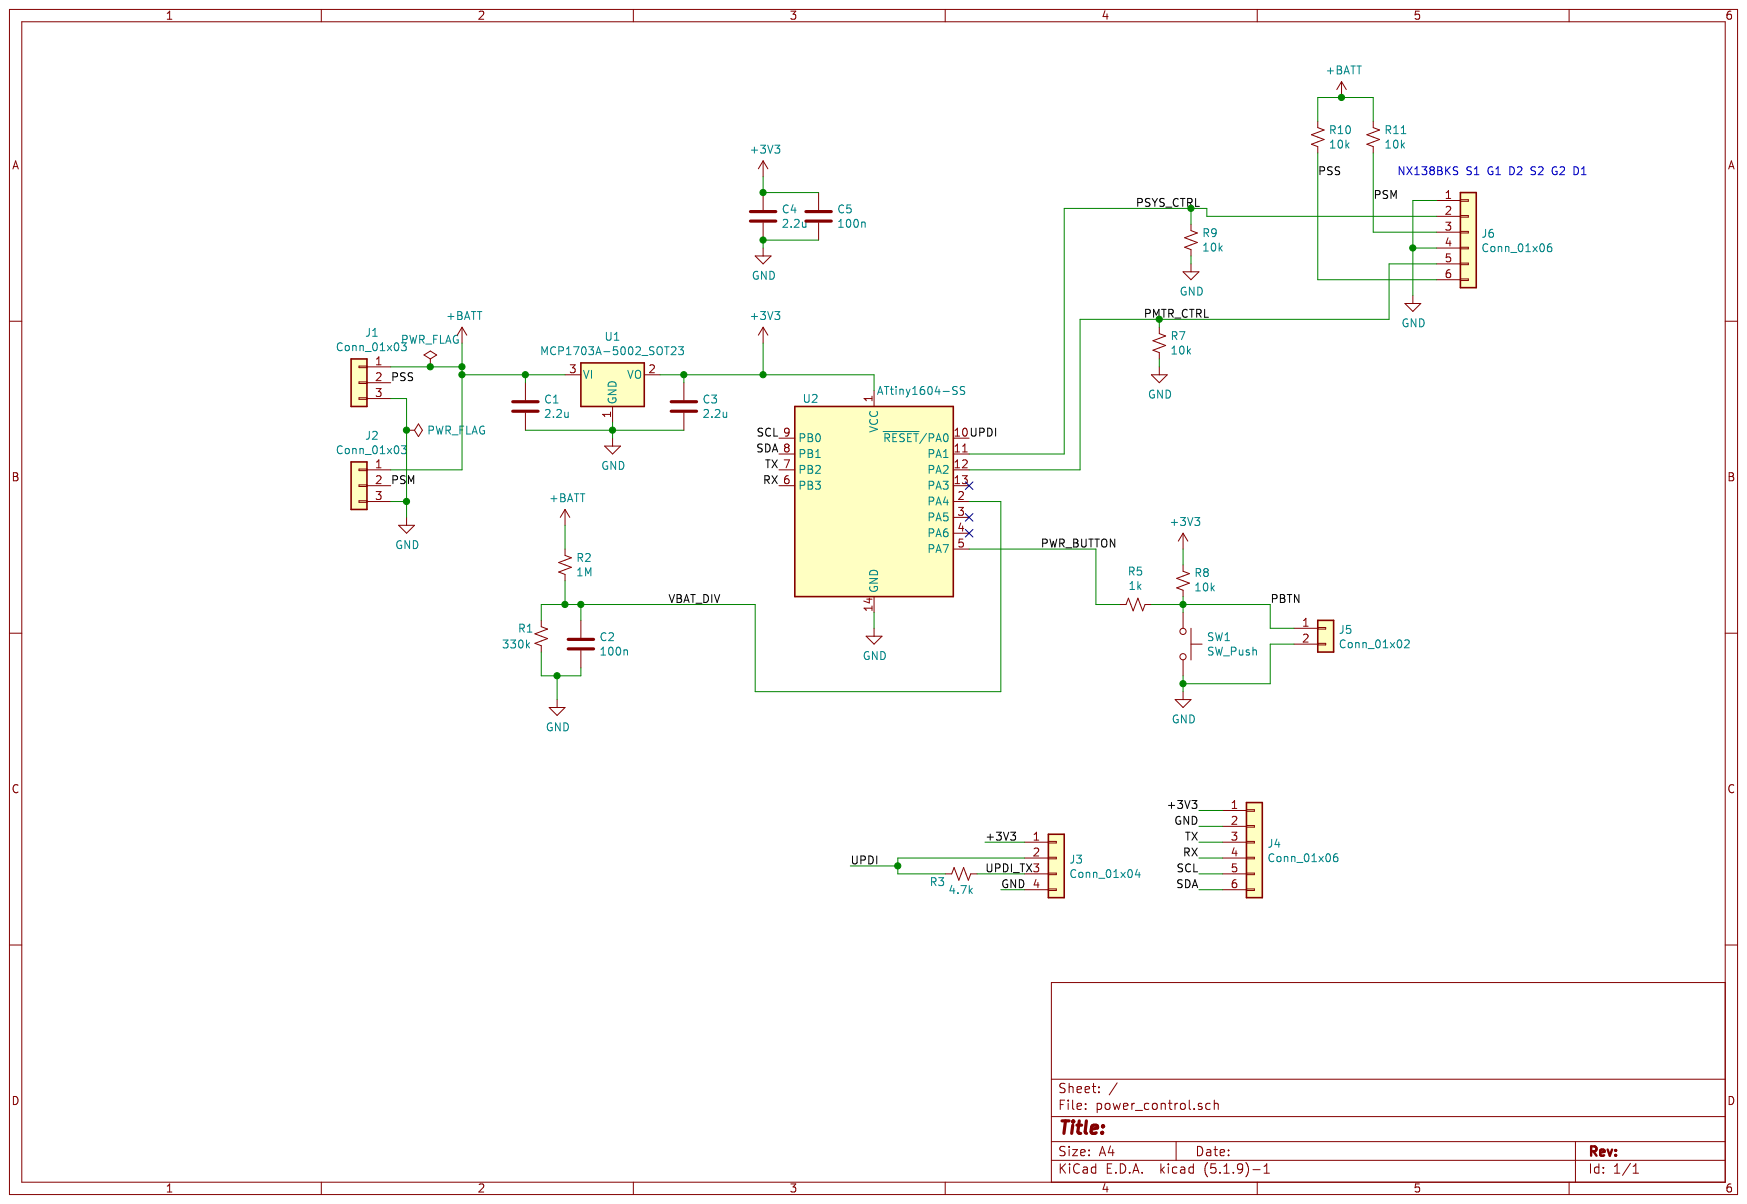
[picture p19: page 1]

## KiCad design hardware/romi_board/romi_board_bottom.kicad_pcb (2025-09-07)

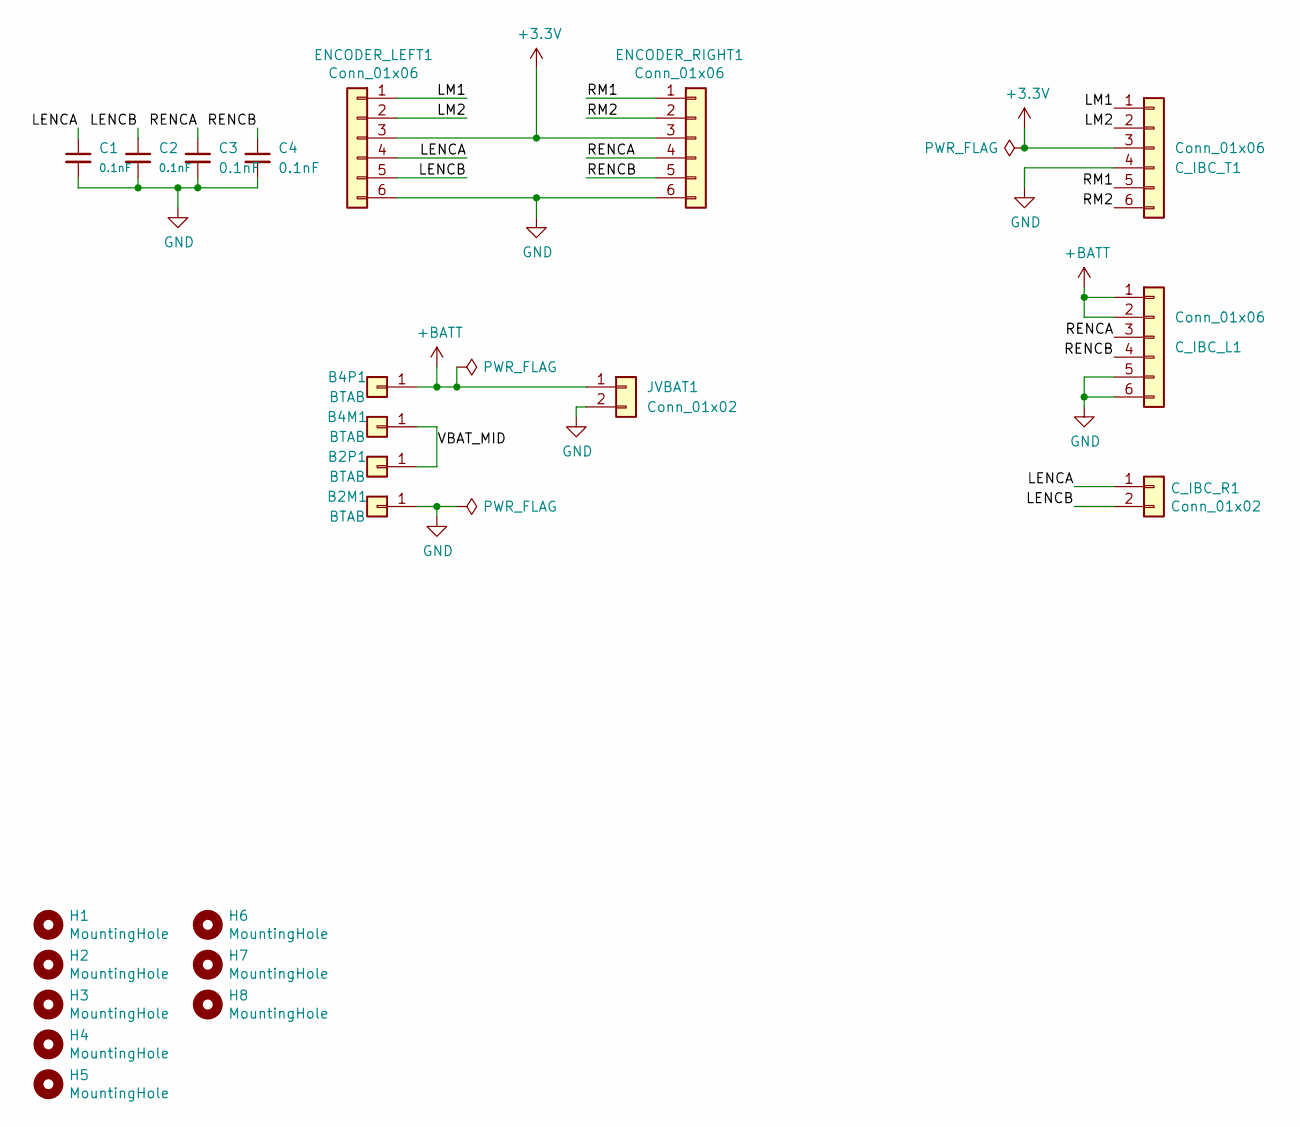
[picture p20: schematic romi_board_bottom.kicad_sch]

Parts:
B2M1, B2P1, B4M1, B4P1: BTAB; romi_battery_tab
C1, C2, C3, C4: 0.1nF; C_0805_2012Metric_Pad1.18x1.45mm_HandSolder
C_IBC_L1: Conn_01x06; PinHeader_1x06_P2.54mm_Vertical
C_IBC_R1: Conn_01x02; PinHeader_1x02_P2.54mm_Vertical
C_IBC_T1: Conn_01x06; PinHeader_1x06_P2.54mm_Vertical
ENCODER_LEFT1: Conn_01x06; PinHeader_1x06_P2.54mm_Vertical
ENCODER_RIGHT1: Conn_01x06; PinHeader_1x06_P2.54mm_Vertical
H1, H2, H3, H4, H5, H6: MountingHole; MountingHole_2.5mm
H7, H8: MountingHole; MountingHole_6mm
JVBAT1: Conn_01x02; PinHeader_1x02_P2.54mm_Vertical

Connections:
+3.3V: C_IBC_T1.3, ENCODER_LEFT1.3, ENCODER_RIGHT1.3
+BATT: B4P1.1, C_IBC_L1.1, C_IBC_L1.2, JVBAT1.1
/LENCA: C1.1, C_IBC_R1.1, ENCODER_LEFT1.4
/LENCB: C2.1, C_IBC_R1.2, ENCODER_LEFT1.5
/LM1: C_IBC_T1.1, ENCODER_LEFT1.1
/LM2: C_IBC_T1.2, ENCODER_LEFT1.2
/RENCA: C3.1, C_IBC_L1.3, ENCODER_RIGHT1.4
/RENCB: C4.1, C_IBC_L1.4, ENCODER_RIGHT1.5
/RM1: C_IBC_T1.5, ENCODER_RIGHT1.1
/RM2: C_IBC_T1.6, ENCODER_RIGHT1.2
/VBAT_MID: B2P1.1, B4M1.1
GND: B2M1.1, C1.2, C2.2, C3.2, C4.2, C_IBC_L1.5, C_IBC_L1.6, C_IBC_T1.4, ENCODER_LEFT1.6, ENCODER_RIGHT1.6, JVBAT1.2

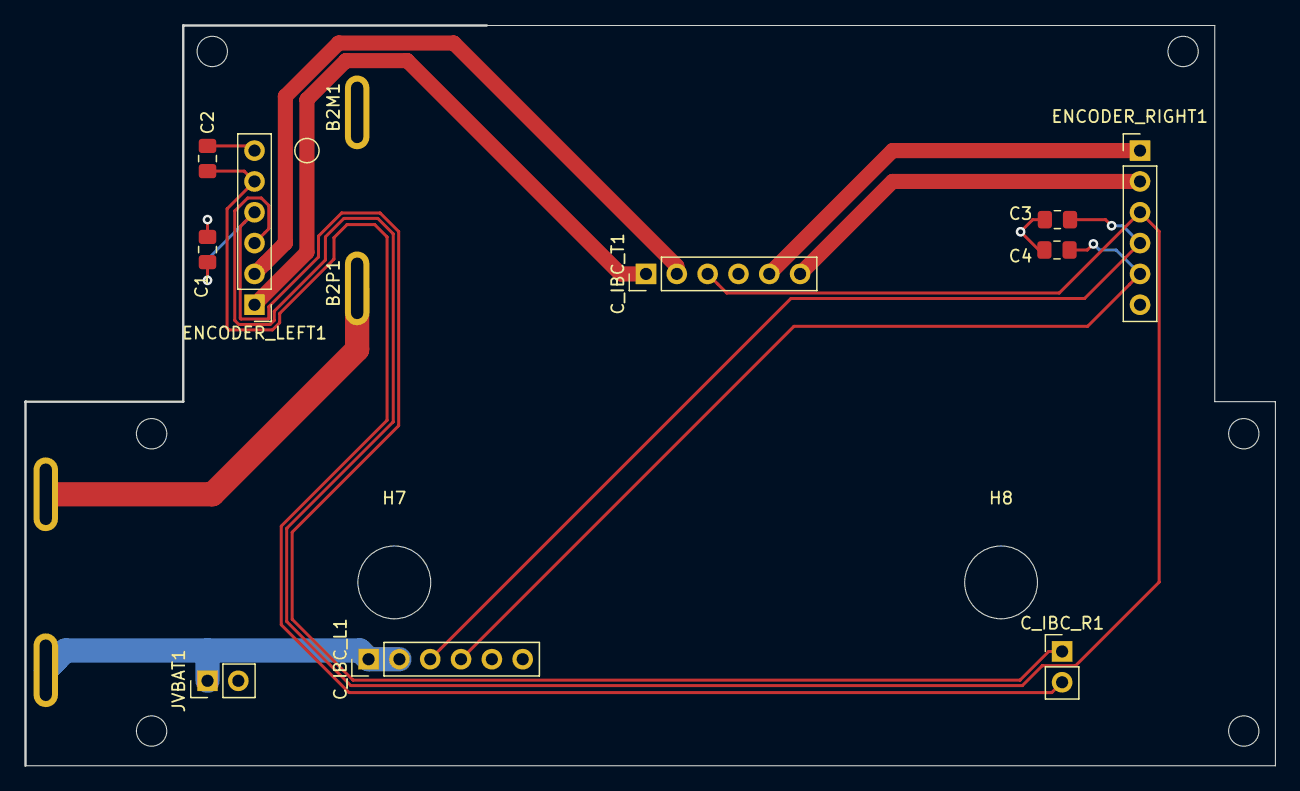
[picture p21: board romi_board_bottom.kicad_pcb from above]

Board: 2 copper layers, 103.0 x 61.0 mm, 22 parts (0 on the bottom side), 12 nets.

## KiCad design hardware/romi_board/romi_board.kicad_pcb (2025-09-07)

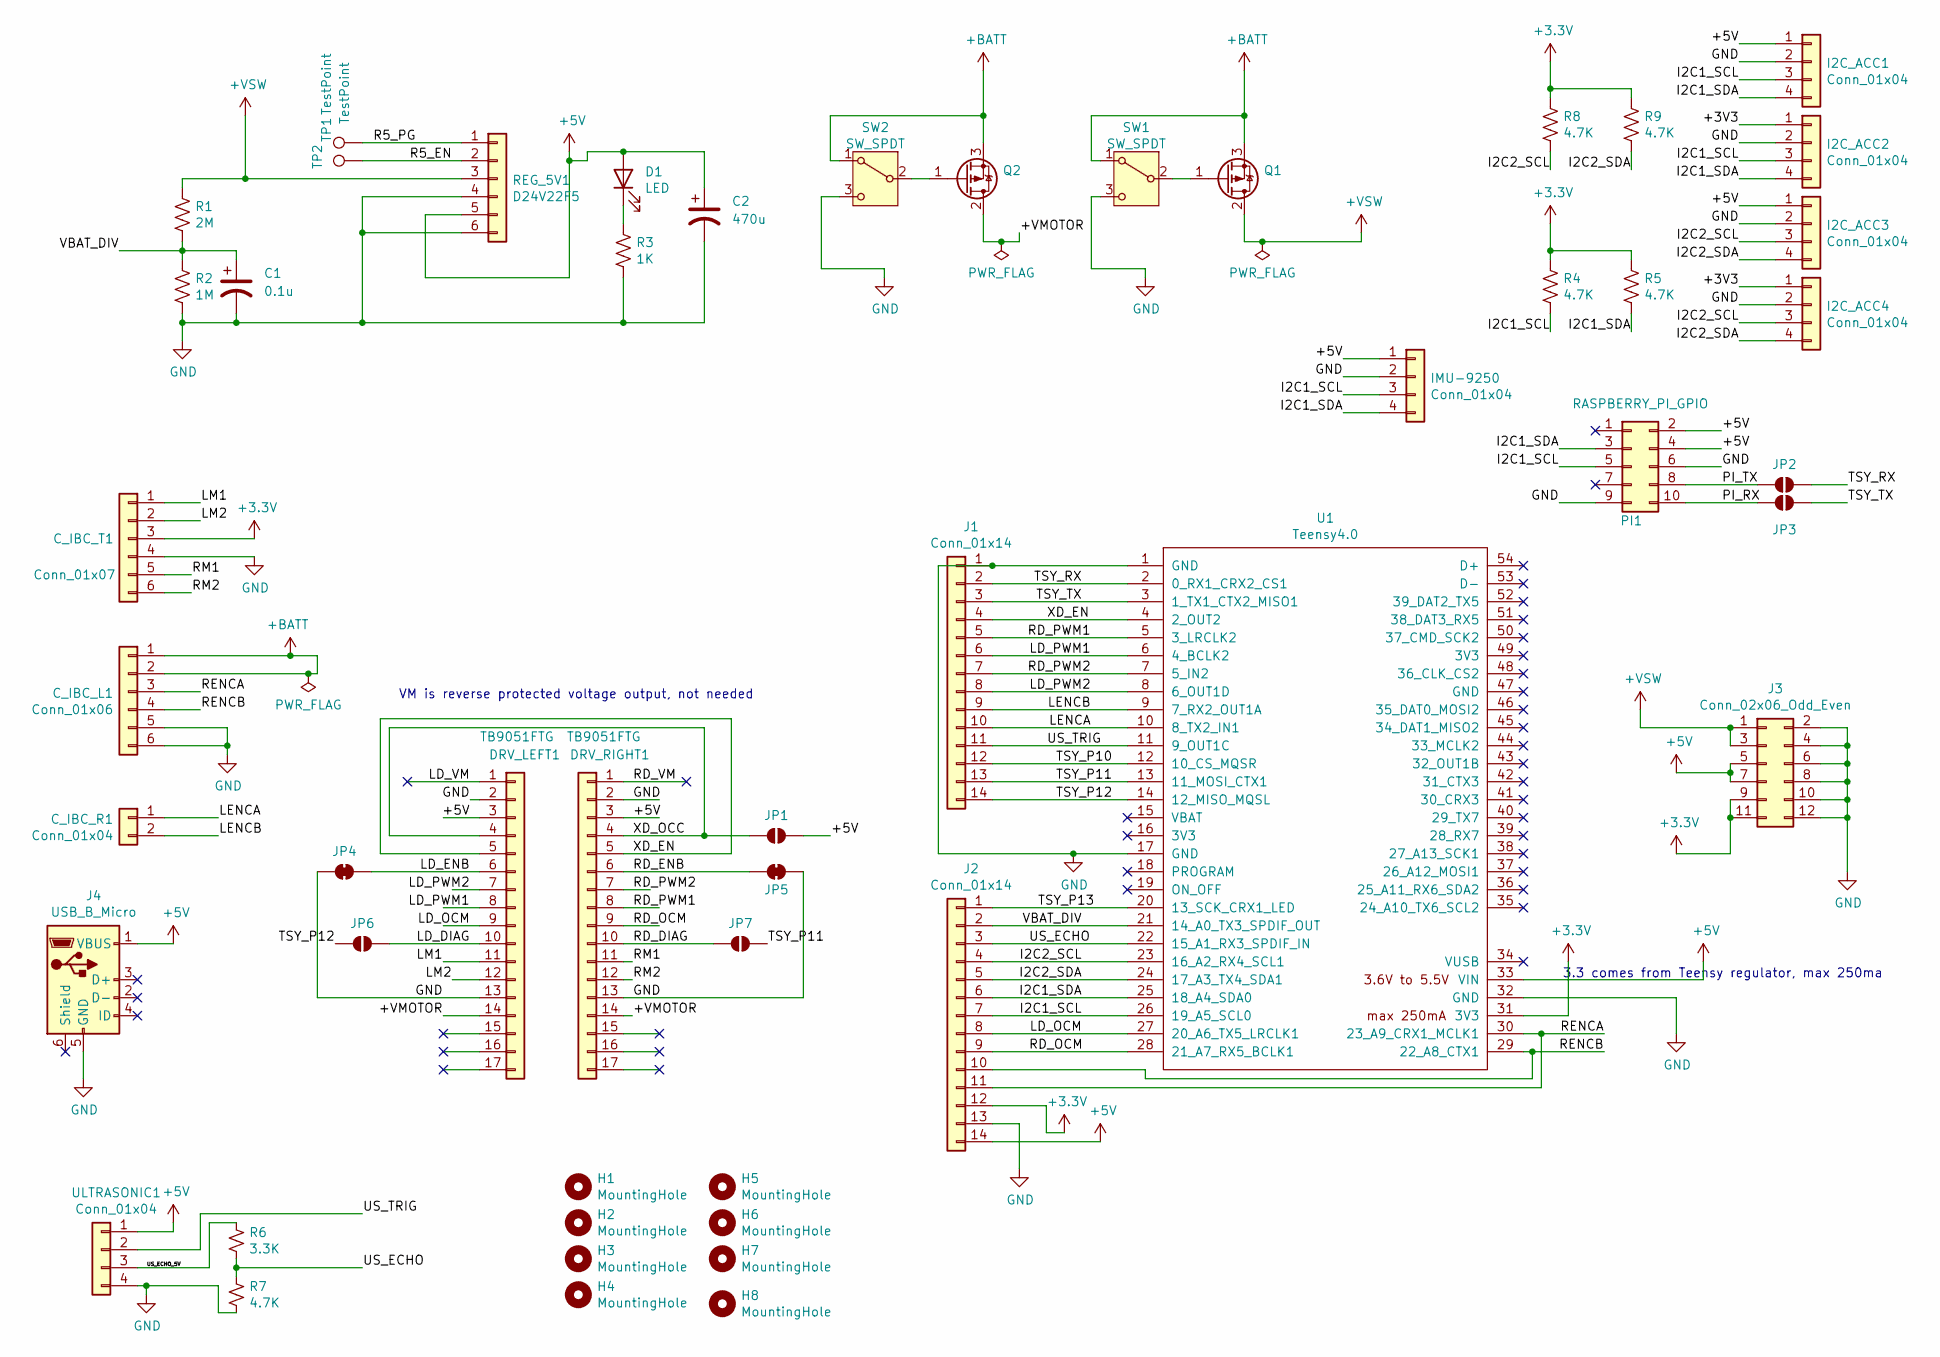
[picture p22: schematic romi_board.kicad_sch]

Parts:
C1: 0.1u; C_Disc_D5.0mm_W2.5mm_P5.00mm
C2: 470u; CP_Radial_D6.3mm_P2.50mm
C_IBC_L1: Conn_01x06; PinHeader_1x06_P2.54mm_Vertical
C_IBC_R1: Conn_01x04; PinHeader_1x02_P2.54mm_Vertical
C_IBC_T1: Conn_01x07; PinHeader_1x06_P2.54mm_Vertical
D1: LED; LED_D5.0mm
DRV_LEFT1: TB9051FTG; TB9051FTG_db
DRV_RIGHT1: TB9051FTG; TB9051FTG_db
H1, H2, H3, H4: MountingHole; MountingHole_2.5mm
H5, H6, H7, H8: MountingHole; MountingHole_6mm_passthrough
I2C_ACC1, I2C_ACC2, I2C_ACC3, I2C_ACC4: Conn_01x04; PinHeader_1x04_P2.54mm_Vertical
IMU-9250: Conn_01x04; MPU9250_BB
J1, J2: Conn_01x14; PinHeader_1x14_P2.54mm_Vertical
J3: Conn_02x06_Odd_Even; PinHeader_2x06_P2.54mm_Vertical
J4: USB_B_Micro; USB_Micro-B_Molex_47346-0001
JP1, JP2, JP3, JP6, JP7: SolderJumper_2_Open; SolderJumper-2_P1.3mm_Open_RoundedPad1.0x1.5mm
JP4, JP5: SolderJumper_2_Bridged; SolderJumper-2_P1.3mm_Bridged_RoundedPad1.0x1.5mm
PI1: RASPBERRY_PI_GPIO; PinHeader_2x05_P2.54mm_Vertical
Q1, Q2: Q_PMOS_DGS; TO-251-3_Vertical
R1: 2M; R_Axial_DIN0309_L9.0mm_D3.2mm_P2.54mm_Vertical
R2: 1M; R_Axial_DIN0309_L9.0mm_D3.2mm_P2.54mm_Vertical
R3: 1K; R_Axial_DIN0309_L9.0mm_D3.2mm_P2.54mm_Vertical
R4, R5, R7, R8, R9: 4.7K; R_Axial_DIN0309_L9.0mm_D3.2mm_P2.54mm_Vertical
R6: 3.3K; R_Axial_DIN0309_L9.0mm_D3.2mm_P2.54mm_Vertical
REG_5V1: D24V22F5; D24V2F5_bb
SW1, SW2: SW_SPDT; Switch
TP1, TP2: TestPoint; TestPoint_Pad_D2.0mm
U1: Teensy4.0; Teensy40_simple
ULTRASONIC1: Conn_01x04; PinHeader_1x04_P2.54mm_Vertical

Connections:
+5V: C2.1, D1.2 (A), DRV_LEFT1.3, DRV_RIGHT1.3, I2C_ACC1.1, I2C_ACC3.1, IMU-9250.1, J2.14, J3.5, J3.7, J4.1 (VBUS), JP1.1 (A), PI1.2, PI1.4, REG_5V1.5, U1.33 (VIN), ULTRASONIC1.1
+BATT: C_IBC_L1.1, C_IBC_L1.2, Q1.3 (S), Q2.3 (S), SW1.1 (A), SW2.1 (A)
+VSW: J3.1, J3.3, Q1.2 (D), R1.1, REG_5V1.3
/+VMOTOR: DRV_LEFT1.14, DRV_RIGHT1.14, Q2.2 (D)
/I2C1_SCL: I2C_ACC1.3, I2C_ACC2.3, IMU-9250.3, J2.7, PI1.5, R4.2, U1.26 (19_A5_SCL0)
/I2C1_SDA: I2C_ACC1.4, I2C_ACC2.4, IMU-9250.4, J2.6, PI1.3, R5.2, U1.25 (18_A4_SDA0)
/I2C2_SCL: I2C_ACC3.3, I2C_ACC4.3, J2.4, R8.2, U1.23 (16_A2_RX4_SCL1)
/I2C2_SDA: I2C_ACC3.4, I2C_ACC4.4, J2.5, R9.2, U1.24 (17_A3_TX4_SDA1)
/LD_DIAG: DRV_LEFT1.10, JP6.1 (A)
/LD_ENB: DRV_LEFT1.6, JP4.2 (B)
/LD_OCM: DRV_LEFT1.9, J2.8, U1.27 (20_A6_TX5_LRCLK1)
/LD_PWM1: DRV_LEFT1.8, J1.6, U1.6 (4_BCLK2)
/LD_PWM2: DRV_LEFT1.7, J1.8, U1.8 (6_OUT1D)
/LD_VM: DRV_LEFT1.1
/LENCA: C_IBC_R1.1, J1.10, U1.10 (8_TX2_IN1)
/LENCB: C_IBC_R1.2, J1.9, U1.9 (7_RX2_OUT1A)
/LM1: C_IBC_T1.1, DRV_LEFT1.11
/LM2: C_IBC_T1.2, DRV_LEFT1.12
/PI_RX: JP3.1 (A), PI1.10
/PI_TX: JP2.1 (A), PI1.8
/R5_EN: REG_5V1.2, TP2.1
/R5_PG: REG_5V1.1, TP1.1
/RD_DIAG: DRV_RIGHT1.10, JP7.2 (B)
/RD_ENB: DRV_RIGHT1.6, JP5.2 (B)
/RD_OCM: DRV_RIGHT1.9, J2.9, U1.28 (21_A7_RX5_BCLK1)
/RD_PWM1: DRV_RIGHT1.8, J1.5, U1.5 (3_LRCLK2)
/RD_PWM2: DRV_RIGHT1.7, J1.7, U1.7 (5_IN2)
/RD_VM: DRV_RIGHT1.1
/RENCA: C_IBC_L1.3, J2.11, U1.30 (23_A9_CRX1_MCLK1)
/RENCB: C_IBC_L1.4, J2.10, U1.29 (22_A8_CTX1)
/RM1: C_IBC_T1.5, DRV_RIGHT1.11
/RM2: C_IBC_T1.6, DRV_RIGHT1.12
/TSY_P10: J1.12, U1.12 (10_CS_MQSR)
/TSY_P11: J1.13, JP7.1 (A), U1.13 (11_MOSI_CTX1)
/TSY_P12: J1.14, JP6.2 (B), U1.14 (12_MISO_MQSL)
/TSY_P13: J2.1, U1.20 (13_SCK_CRX1_LED)
/TSY_RX: J1.2, JP2.2 (B), U1.2 (0_RX1_CRX2_CS1)
/TSY_TX: J1.3, JP3.2 (B), U1.3 (1_TX1_CTX2_MISO1)
/US_ECHO: J2.3, R6.2, R7.1, U1.22 (15_A1_RX3_SPDIF_IN)
/US_ECHO_5V: R6.1, ULTRASONIC1.3
/US_TRIG: J1.11, U1.11 (9_OUT1C), ULTRASONIC1.2
/VBAT_DIV: C1.1, J2.2, R1.2, R2.1, U1.21 (14_A0_TX3_SPDIF_OUT)
/XD_EN: DRV_LEFT1.5, DRV_RIGHT1.5, J1.4, U1.4 (2_OUT2)
/XD_OCC: DRV_LEFT1.4, DRV_RIGHT1.4, JP1.2 (B)
GND: C1.2, C2.2, C_IBC_L1.5, C_IBC_L1.6, C_IBC_T1.4, DRV_LEFT1.2, DRV_LEFT1.13, DRV_RIGHT1.2, DRV_RIGHT1.13, I2C_ACC1.2, I2C_ACC2.2, I2C_ACC3.2, I2C_ACC4.2, IMU-9250.2, J1.1, J2.13, J3.2, J3.4, J3.6, J3.8, J3.10, J3.12, J4.5 (GND), JP4.1 (A), JP5.1 (A), PI1.6, PI1.9, R2.2, R3.2, R7.2, REG_5V1.4, REG_5V1.6, SW1.3 (C), SW2.3 (C), U1.1 (GND), U1.17 (GND), U1.32 (GND), ULTRASONIC1.4
unnamed: D1.1 (K), R3.1
unnamed: Q1.1 (G), SW1.2 (B)
unnamed: Q2.1 (G), SW2.2 (B)

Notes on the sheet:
3.3 comes from Teensy regulator, max 250ma
VM is reverse protected voltage output, not needed

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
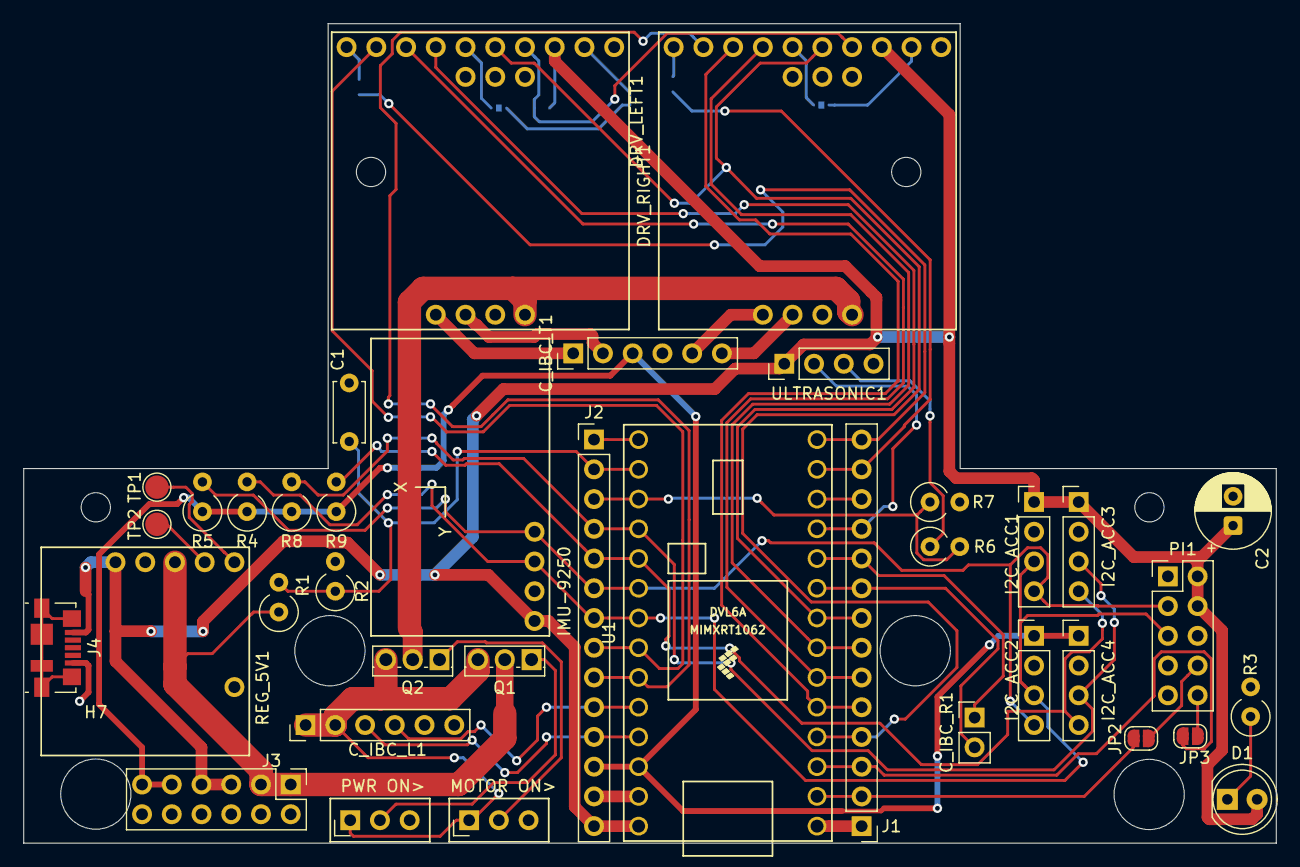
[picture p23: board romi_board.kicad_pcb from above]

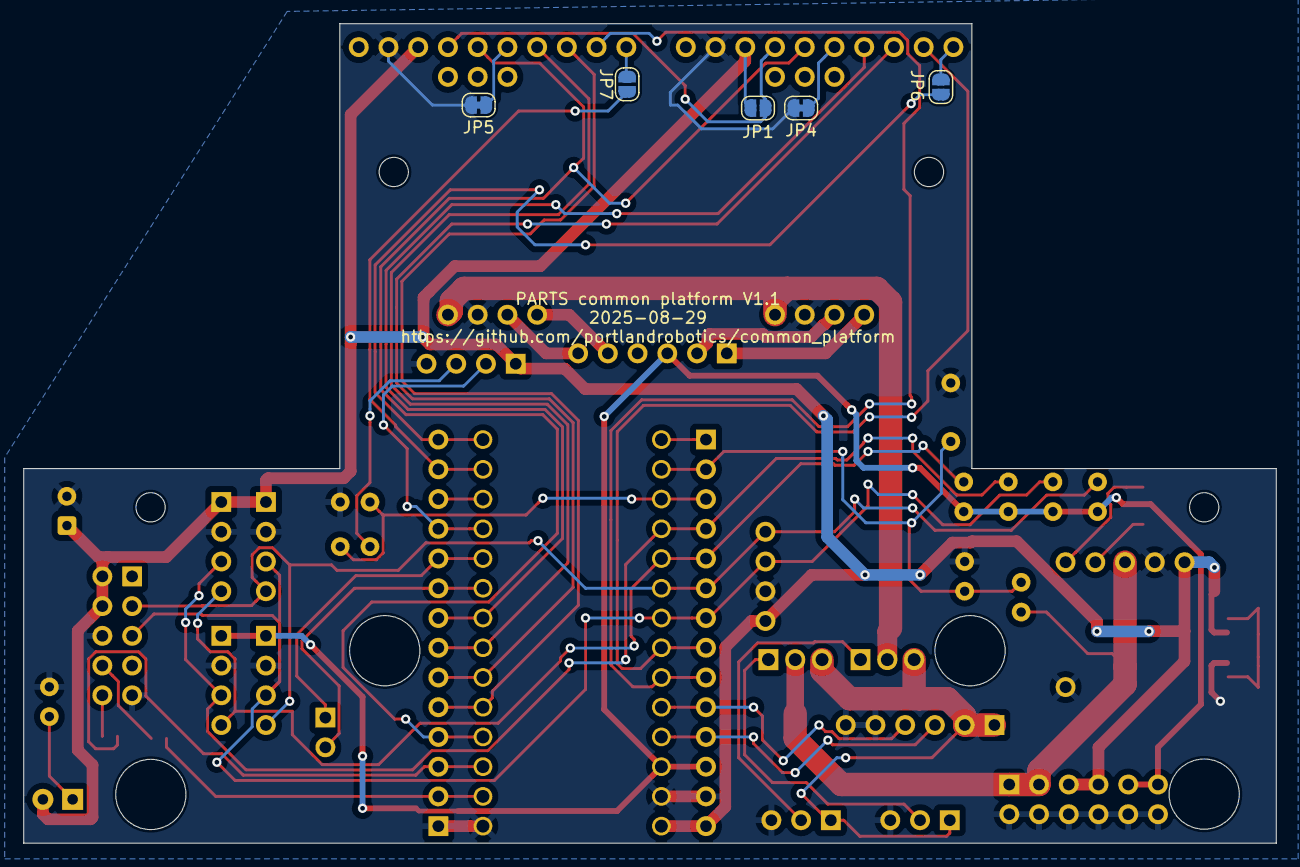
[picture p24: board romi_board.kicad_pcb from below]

Board: 2 copper layers, 107.0 x 70.0 mm, 51 parts (5 on the bottom side), 47 nets.

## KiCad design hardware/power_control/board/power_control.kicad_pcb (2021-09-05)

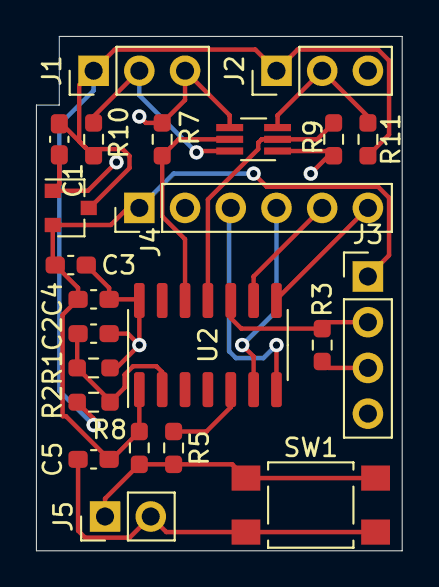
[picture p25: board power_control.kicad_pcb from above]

Board: 2 copper layers, 20.3 x 28.6 mm, 23 parts (0 on the bottom side), 16 nets.

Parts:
C1, C2, C3, C4, C5: C; C_0603_1608Metric_Pad1.08x0.95mm_HandSolder
J1, J2: Conn_01x03; PinHeader_1x03_P2.54mm_Vertical
J3: Conn_01x04; PinHeader_1x04_P2.54mm_Vertical
J4: Conn_01x06; PinHeader_1x06_P2.54mm_Vertical
J5: Conn_01x02; PinHeader_1x02_P2.54mm_Vertical
J6: Conn_01x06; SOT-363_SC-70-6_Handsoldering
R1, R2, R3, R5, R7, R8, R9, R10, R11: R_Small_US; R_0603_1608Metric_Pad0.98x0.95mm_HandSolder
SW1: SW_Push; SW_SPST_TL3305A
U1: MCP1703A-5002_SOT23; SOT-23
U2: ATtiny1604-SS; SOIC-14_3.9x8.7mm_P1.27mm

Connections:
+3V3: C3.1, C4.1, C5.1, J3.1, J4.1, R8.2, U1.2, U2.1
+BATT: C1.1, J1.1, J2.1, R2.1, R10.1, R11.1, U1.3
/PBTN: J5.1, R5.2, R8.1, SW1.1
/PMTR_CTRL: J6.5, R7.1, U2.12
/PSM: J2.2, J6.3, R11.2
/PSS: J1.2, J6.6, R10.2
/PSYS_CTRL: J6.2, R9.1, U2.11
/PWR_BUTTON: R5.1, U2.5
/RX: J4.4, U2.6
/SCL: J4.5, U2.9
/SDA: J4.6, U2.8
/TX: J4.3, U2.7
/UPDI: J3.2, R3.2, U2.10
/UPDI_TX: J3.3, R3.1
/VBAT_DIV: C2.1, R1.1, R2.2, U2.2
GND: C1.2, C2.2, C3.2, C4.2, C5.2, J1.3, J2.3, J3.4, J4.2, J5.2, J6.1, J6.4, R1.2, R7.2, R9.2, SW1.2, U1.1, U2.14

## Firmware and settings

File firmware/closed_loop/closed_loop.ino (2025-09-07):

/**
 * @file closed_loop.ino
 * @brief Firmware for a closed-loop motor control system with optional ROS integration.
 *
 * This firmware is designed to control a robot with two motors, using PID controllers
 * for precise speed and position control. It supports two modes of operation:
 * - **Standalone Mode**: The robot operates independently, using serial commands for control.
 * - **ROS Mode**: The robot integrates with the Robot Operating System (ROS) for remote control
 *   and communication via the micro-ROS framework.
 *
 * ## Features:
 * - **Motor Control**: PID-based speed control for left and right motors.
 * - **Odometry**: Tracks the robot's position and orientation using encoder feedback.
 * - **Command Parsing**: Supports serial commands for motor control, PID tuning, and state reset.
 * - **ROS Integration**: Subscribes to `cmd_vel` messages for velocity commands and manages
 *   connection to a ROS agent.
 * - **Safety Features**: Includes overcurrent protection and motor disable functionality.
 * - **Status Reporting**: Periodically outputs robot status, including odometry and motor speeds.
 *
 * ## Code Structure:
 * - **Global Configuration**: Pin definitions, ROS mode selection, and debug settings.
 * - **Classes**:
 *   - `PidControl`: Implements a PID controller for motor speed control.
 *   - `MotorControl`: Manages motor speed, encoder feedback, and PWM output.
 *   - `Point` and `Motion`: Handle robot position and orientation tracking.
 * - **Global Objects**: Instances of `MotorControl`, `Motion`, and `RobotState` for managing
 *   the robot's state and behavior.
 * - **ROS-Specific Logic**: Handles ROS communication, including agent connection and message
 *   subscription.
 * - **Main Functions**:
 *   - `setup()`: Initializes hardware, ROS (if enabled), and robot state.
 *   - `loop()`: Main control loop, handling sensor updates, motor control, ROS communication,
 *     and serial command processing.
 *   - `drivecontrol()`: Calculates motor target speeds based on ROS or standalone commands.
 *   - `parseCommand()`: Processes serial commands for robot control and configuration.
 *
 * ## Usage:
 * - Set `#define ROS` to `1` for ROS mode or `0` for standalone mode.
 * - In standalone mode, use serial commands to control the robot (e.g., `M` to toggle motors,
 *   `F` to move forward, `L`/`R` to turn).
 * - In ROS mode, ensure a ROS agent is running and publishing `cmd_vel` messages.
 *
 * ## Notes:
 * - Ensure proper tuning of PID parameters for optimal performance.
 * - Adjust hardware-specific constants (e.g., encoder counts per revolution, wheel diameter)
 *   as needed for your robot.
 */

// Pin Definitions
const int PIN_XD_EN = 2;
const int PIN_RD_PWM1 = 3;
const int PIN_LD_PWM1 = 4;
const int PIN_RD_PWM2 = 5;
const int PIN_LD_PWM2 = 6;
const int PIN_LENCB = 7;
const int PIN_LENCA = 8;
const int PIN_US_TRIG = 9;
const int PIN_VBAT = 14;
const int PIN_US_ECHO = 15;
const int PIN_LD_OCM = 20;
const int PIN_RD_OCM = 21;
const int PIN_RENCB = 22;
const int PIN_RENCA = 23;
const int LED_PIN = 13;

#include "setup.h"  // Include global configuration header
#include "PidControl.h"
#include "MotorControl.h"
#include "RobotState.h"
#include "Motion.h"

#include <Wire.h>
// #include <math.h>

#if ROS
#include "RosInterface.h"
#endif  // ROS

// --- Global Objects ---
RobotState robotState;
MotorControl leftMotor(PIN_LD_OCM, PIN_LENCB, PIN_LENCA, PIN_LD_PWM2, PIN_LD_PWM1, "Left");
MotorControl rightMotor(PIN_RD_OCM, PIN_RENCA, PIN_RENCB, PIN_RD_PWM1, PIN_RD_PWM2, "Right");
Motion motion;

void robotState_reset() {
  robotState.targetLinearVelocity = 0.0f;
  robotState.targetAngularVelocity = 0.0f;
  robotState.move = false;
  // cmdDrive = true; // Should reset keep motors enabled? Maybe not.
#if !ROS
  robotState.leftTargetDistance = 0;
  robotState.rightTargetDistance = 0;
  robotState.targetHeading = 0.0f;
  robotState.isMoving = false;
  robotState.corr = 0.0f;
#endif
}

// --- Interrupt Service Routines for Encoders ---
// These ISRs directly manipulate the public volatile members of the global motor objects.

void leftEncoderInterrupt() {
  // Read current state of Left Motor's Encoder A and B pins
  // Note: digitalRead inside ISR is generally acceptable on fast MCUs like Teensy
  int8_t current_enc_val = (digitalRead(PIN_LENCA) ? 2 : 0) | (digitalRead(PIN_LENCB) ? 1 : 0);

  // Quadrature logic
  int8_t last_A_bit = (leftMotor.lastEnc >> 1) & 1;
  int8_t last_B_bit = leftMotor.lastEnc & 1;
  int8_t current_A_bit = (current_enc_val >> 1) & 1;
  int8_t current_B_bit = current_enc_val & 1;
  int8_t dir = (last_A_bit ^ current_B_bit) - (current_A_bit ^ last_B_bit);

  if (dir != 0) {
    // Physical forward rotation of the left motor causes its counter to decrease
    // (due to A leading B with the current XOR logic), so we invert dir here
    // to make the counter increase for forward motion.
    leftMotor.counter -= dir;          // Changed from += to -= to flip the direction for the left motor
    leftMotor.lastEncTime = micros();  // Update time of the edge
  }
  leftMotor.lastEnc = current_enc_val;  // Update last known state
}

void rightEncoderInterrupt() {
  // Read current state of Right Motor's Encoder A and B pins
  int8_t current_enc_val = (digitalRead(PIN_RENCA) ? 2 : 0) | (digitalRead(PIN_RENCB) ? 1 : 0);

  // Quadrature logic
  int8_t last_A_bit = (rightMotor.lastEnc >> 1) & 1;
  int8_t last_B_bit = rightMotor.lastEnc & 1;
  int8_t current_A_bit = (current_enc_val >> 1) & 1;
  int8_t current_B_bit = current_enc_val & 1;
  int8_t dir = (last_A_bit ^ current_B_bit) - (current_A_bit ^ last_B_bit);

  if (dir != 0) {
    rightMotor.counter += dir;
    rightMotor.lastEncTime = micros();
  }
  rightMotor.lastEnc = current_enc_val;
}


// --- ROS Specific Section ---
#if !ROS
// Differential PID only needed for non-ROS heading control during F commands
PidControl differential;
#endif

// --- Command Parsing ---
/**
 * @brief Parse and execute serial commands
 * Common commands: M, X
 * Non-ROS commands: L, R, F, V, P, I, D
 */
void parseCommand(const char *const cmd) {
  if (!cmd || !cmd[0]) {
    SERIAL_OUT.println("Error: Empty command");
    return;
  }

  float value = (cmd[1] != '\0') ? atof(cmd + 1) : 0.0f;
  bool commandProcessed = false;  // Flag to check if any case matched

  switch (cmd[0]) {
    case 'M':  // Toggle motor drive
      robotState.cmdDrive = !robotState.cmdDrive;
      digitalWrite(PIN_XD_EN, robotState.cmdDrive ? HIGH : LOW);  // Apply enable immediately
      SERIAL_OUT.print("Motor Drive ");
      SERIAL_OUT.println(robotState.cmdDrive ? "Enabled" : "Disabled");
      commandProcessed = true;
      break;

    case 'X':  // Reset state
      leftMotor.resetCounter();
      rightMotor.resetCounter();
      motion.reset();
      robotState_reset();
#if !ROS
      differential.reset();
#endif
      SERIAL_OUT.println("Reset state");
      commandProcessed = true;
      break;

#if !ROS
    // --- Non-ROS Specific Commands ---
    case 'L':  // Turn Left (degrees)
    case 'R':  // Turn Right (degrees)
      {
        float angleRad = value * M_PI / 180.0f;
        float wheelTravel = (angleRad * Motion::TRACK_WIDTH) / 2.0f;
        // Use public constant from MotorControl
        float counts = wheelTravel / MotorControl::METERS_PER_COUNT;

        noInterrupts();  // Protect target distance updates
        if (cmd[0] == 'L') {
          robotState.leftTargetDistance -= static_cast<int32_t>(counts);
          robotState.rightTargetDistance += static_cast<int32_t>(counts);
        } else {
          robotState.leftTargetDistance += static_cast<int32_t>(counts);
          robotState.rightTargetDistance -= static_cast<int32_t>(counts);
        }
        interrupts();
        robotState.isMoving = false;  // This is a turn, not forward motion
        robotState.move = true;       // A move command is active
        SERIAL_OUT.print("Turn ");
        SERIAL_OUT.print(value);
        SERIAL_OUT.println(" deg");
        commandProcessed = true;
      }
      break;

    case 'F':  // Move Forward/Backward (meters)
      {
        // Use public constant from MotorControl
        float counts = value / MotorControl::METERS_PER_COUNT;
        noInterrupts();  // Protect target distance updates
        robotState.leftTargetDistance += static_cast<int32_t>(counts);
        robotState.rightTargetDistance += static_cast<int32_t>(counts);
        interrupts();
        robotState.targetHeading = motion.getTheta();  // Target current heading
        robotState.isMoving = true;                    // This is forward motion
        robotState.move = true;                        // A move command is active
        differential.reset();                          // Reset heading PID for new move
        SERIAL_OUT.print("Move ");
        SERIAL_OUT.print(value);
        SERIAL_OUT.println(" m");
        commandProcessed = true;
      }
      break;

    case 'V':  // Set Max Speed (m/s)
      // Use public constant from MotorControl
      if (value > 0.0f && value <= MotorControl::MAX_SPEED) {
        robotState.maxSpeed = value;
        SERIAL_OUT.print("Max speed set to: ");
        SERIAL_OUT.println(value);
        commandProcessed = true;
      } else {
        SERIAL_OUT.print("Error: Speed must be > 0 and <= ");
        SERIAL_OUT.println(MotorControl::MAX_SPEED);  // Use public constant
      }
      break;

    // Differential PID Tuning Commands (Non-ROS)
    case 'P':
      differential.P = value;
      commandProcessed = true;
      SERIAL_OUT.print("Diff P=");
      SERIAL_OUT.println(value);
      break;
    case 'I':
      differential.I = value;
      commandProcessed = true;
      SERIAL_OUT.print("Diff I=");
      SERIAL_OUT.println(value);
      break;
    case 'D':
      differential.D = value;
      commandProcessed = true;
      SERIAL_OUT.print("Diff D=");
      SERIAL_OUT.println(value);
      break;

#endif  // !ROS Specific Commands

    default:
      SERIAL_OUT.print("Error: Unknown command '");
      SERIAL_OUT.print(cmd[0]);
      SERIAL_OUT.println("'");
      commandProcessed = true;  // We processed it by saying it's unknown
  }

  if (!commandProcessed) {
    // This case might happen if a command is defined for one mode but not the other
    SERIAL_OUT.print("Error: Command '");
    SERIAL_OUT.print(cmd[0]);
    SERIAL_OUT.println("' not available in this mode (ROS=");
    SERIAL_OUT.print(ROS);
    SERIAL_OUT.println(")");
  }
}

// --- Setup ---
void setup() {
  // Common Serial Initialization
  SERIAL_OUT.begin(115200);
  SERIAL_OUT.println("--- Robot Firmware Starting ---");
  SERIAL_OUT.print("ROS Mode: ");
  SERIAL_OUT.println(ROS);

#if ROS
  // ROS Specific Setup
  SERIAL_OUT.println("Setting up micro-ROS...");
  setup_ROS();
  pinMode(LED_PIN, OUTPUT);
  digitalWrite(LED_PIN, LOW);  // LED off initially
  delay(1000);                 // Short delay before trying agent
  // state = WAITING_AGENT;
  SERIAL_OUT.println("Waiting for micro-ROS Agent...");
#else
  // Non-ROS Specific Setup
  pinMode(LED_PIN, OUTPUT);
  digitalWrite(LED_PIN, LOW);
  SERIAL_OUT.println("Running in Standalone Mode.");
  // Configure differential PID (only used in non-ROS)
  differential.setLimits(0.5, 0.2);      // Limit correction effect
  differential.setFiltering(0.01, 0.1);  // Add some filtering
  differential.P = 0.8;                  // Might need tuning
  differential.I = 0.01;
  differential.D = 0.05;
#endif

  // Common Hardware Setup
  // Enable encoder pullups
  pinMode(PIN_LENCA, INPUT_PULLUP);
  pinMode(PIN_LENCB, INPUT_PULLUP);
  pinMode(PIN_RENCA, INPUT_PULLUP);
  pinMode(PIN_RENCB, INPUT_PULLUP);

  // Initialize lastEnc states BEFORE attaching interrupts
  // This ensures the first interrupt call has a valid previous state.
  leftMotor.lastEnc = (digitalRead(PIN_LENCA) ? 2 : 0) | (digitalRead(PIN_LENCB) ? 1 : 0);
  rightMotor.lastEnc = (digitalRead(PIN_RENCA) ? 2 : 0) | (digitalRead(PIN_RENCB) ? 1 : 0);
  uint32_t now = micros();
  leftMotor.lastEncTime = now;
  rightMotor.lastEncTime = now;

  // Enable motor drive outputs
  pinMode(PIN_XD_EN, OUTPUT);
  pinMode(PIN_RD_PWM1, OUTPUT);
  pinMode(PIN_LD_PWM1, OUTPUT);
  pinMode(PIN_RD_PWM2, OUTPUT);
  pinMode(PIN_LD_PWM2, OUTPUT);

  // Ensure motors are off and enabled initially
  digitalWrite(PIN_XD_EN, HIGH);  // HIGH likely means enabled for common drivers
  analogWrite(PIN_RD_PWM1, 0);
  analogWrite(PIN_RD_PWM2, 0);
  analogWrite(PIN_LD_PWM1, 0);
  analogWrite(PIN_LD_PWM2, 0);
  // Configure Motor PIDs (Common)
  // These values likely need tuning!
  leftMotor.pid.setLimits(1.0, 0.5);      // Max output, max integral sum
  leftMotor.pid.setFiltering(0.01, 0.1);  // Deadband, D filter coeff
  leftMotor.pid.P = 8.0;
  leftMotor.pid.I = 0.8;
  leftMotor.pid.D = 0.00;

  rightMotor.pid.setLimits(1.0, 0.5);
  rightMotor.pid.setFiltering(0.01, 0.1);
  rightMotor.pid.P = 8.0;
  rightMotor.pid.I = 0.8;
  rightMotor.pid.D = 0.00;

  // Reset state
  leftMotor.resetCounter();
  rightMotor.resetCounter();
  motion.reset();
  robotState_reset();

  // Attach interrupts for encoders
  // Note: digitalPinToInterrupt() is necessary for mapping pin numbers to interrupt numbers.
  attachInterrupt(digitalPinToInterrupt(PIN_LENCA), leftEncoderInterrupt, CHANGE);
  attachInterrupt(digitalPinToInterrupt(PIN_LENCB), leftEncoderInterrupt, CHANGE);
  attachInterrupt(digitalPinToInterrupt(PIN_RENCA), rightEncoderInterrupt, CHANGE);
  attachInterrupt(digitalPinToInterrupt(PIN_RENCB), rightEncoderInterrupt, CHANGE);

  // I2C Setup (Common)
  SERIAL_OUT.println("Initializing I2C and IMU...");
  Wire.begin();
  Wire.beginTransmission(0x68);  // MPU6050 default address
  Wire.write(0x6B);              // PWR_MGMT_1 register
  Wire.write(0x80);              // Reset device
  auto rv = Wire.endTransmission(true);
  SERIAL_OUT.print("IMU Reset returned: ");
  SERIAL_OUT.println(rv);
  delay(100);  // Wait for reset

  Wire.beginTransmission(0x68);
  Wire.write(0x6B);  // PWR_MGMT_1 register
  Wire.write(0x00);  // Wake up device
  rv = Wire.endTransmission(true);
  SERIAL_OUT.print("IMU Wakeup returned: ");
  SERIAL_OUT.println(rv);
  delay(100);

  // Add more IMU config if needed (e.g., setting ranges, DLPF)

  SERIAL_OUT.println("--- Setup Complete ---");
}

// --- Status Printing ---
void printStatus() {
  char buf[128];

  // Print Odometry
  motion.print();

  // Print Motor Speeds (Target vs Actual)
  snprintf(buf, sizeof(buf), "Speed L: Tgt=%.2f Act=%.2f | R: Tgt=%.2f Act=%.2f m/s",
           leftMotor.getTargetSpeed(), leftMotor.getSpeed(),
           rightMotor.getTargetSpeed(), rightMotor.getSpeed());
  SERIAL_OUT.println(buf);

#if !ROS
  // Print Non-ROS specific info
  snprintf(buf, sizeof(buf), "Encoders L: %ld/%ld | R: %ld/%ld",
           leftMotor.getCounter(), robotState.leftTargetDistance,
           rightMotor.getCounter(), robotState.rightTargetDistance);
  SERIAL_OUT.println(buf);

  snprintf(buf, sizeof(buf), "Control: MaxSpd=%.2f HeadTgt=%.1f HeadCorr=%.3f",
           robotState.maxSpeed, robotState.targetHeading * 180.0f / M_PI, robotState.corr);
  SERIAL_OUT.println(buf);
  snprintf(buf, sizeof(buf), "Diff PID: P=%.2f I=%.2f D=%.2f",
           differential.P, differential.I, differential.D);
  SERIAL_OUT.println(buf);
#else
  // Print ROS specific info (if any needed beyond speeds)
  // TODO: figure out what to do for this message
  // snprintf(buf, sizeof(buf), "ROS State: %d | Target Lin=%.2f Ang=%.2f",
  //          currentRosAgentStatus, robotState.targetLinearVelocity, robotState.targetAngularVelocity);
  // SERIAL_OUT.println(buf);
#endif
}

/**
 * Controls the movement of the robot by calculating and setting the target speeds for its left and right motors.
 * The control logic depends on whether the robot is in ROS (Robot Operating System) mode or not.
 *
 * In ROS mode, it converts target linear and angular velocities to wheel velocities using the robot's track width,
 * and optionally applies a speed limit to prevent high speeds.
 *
 * In non-ROS mode, it implements a simple P-controller for position-based control towards target distances,
 * calculates the remaining distance for each wheel and adjusts the velocity accordingly, applies a threshold to stop
 * the robot near the target, and optionally corrects the heading during forward/backward motion using a differential PID controller.
 *
 * Ultimately, it sets the target speeds for the left and right motors, ensuring they are within the robot's maximum speed limits.
 */
void drivecontrol() {
  float leftVelocity = 0.0f;
  float rightVelocity = 0.0f;

  if (!robotState.cmdDrive) {
    // If drive explicitly disabled, ensure motors are set to zero speed
    leftMotor.setTargetSpeed(0.0f);
    rightMotor.setTargetSpeed(0.0f);
    return;  // Don't proceed with control logic
  }

#if ROS
  // ROS mode: Convert target Twist velocities (linear/angular) to wheel velocities
  // Use public constant from Motion
  leftVelocity = robotState.targetLinearVelocity - (robotState.targetAngularVelocity * Motion::TRACK_WIDTH / 2.0f);
  rightVelocity = robotState.targetLinearVelocity + (robotState.targetAngularVelocity * Motion::TRACK_WIDTH / 2.0f);

  // Apply overall speed limit if needed (optional, Twist could command high speeds)
  // float max_vel = max(abs(leftVelocity), abs(rightVelocity));
  // if (max_vel > robotState.maxSpeed) { // Uses RobotState maxSpeed
  //    float scale = robotState.maxSpeed / max_vel;
  //    leftVelocity *= scale;
  //    rightVelocity *= scale;
  // }
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
void loop() {
  const auto nowMicros = micros();

  leftMotor.readCurrent();
  rightMotor.readCurrent();

  // --- Periodic Updates ---
  static auto nextMotionUpdate = nowMicros;
  const unsigned long motionUpdateInterval = 10000;  // 10ms = 100Hz
  if (nowMicros >= nextMotionUpdate) {
    // Update Odometry
    motion.update(leftMotor.getCounter(), rightMotor.getCounter());

    // Update Motor PIDs and apply PWM
    leftMotor.motionUpdate();
    rightMotor.motionUpdate();

    // Calculate next update time, handling potential rollover
    nextMotionUpdate = (nowMicros / motionUpdateInterval + 1) * motionUpdateInterval;
  }

  // --- Drive Control Logic ---
  // This determines the target speeds based on ROS commands or non-ROS targets
  drivecontrol();

  // --- ROS Handling ---
#if ROS
  handleRosAgentState(&robotState);  // Handles connection and spins the executor
#endif

  // --- Serial Command Input ---
  static char cmdbuf[32];  // Increased buffer size
  static size_t cmdbufpos = 0;
  while (SERIAL_OUT.available()) {
    char c = SERIAL_OUT.read();
    if (c == '\n' || c == '\r') {
      if (cmdbufpos > 0) {         // Process only if buffer is not empty
        cmdbuf[cmdbufpos] = '\0';  // Null terminate
        SERIAL_OUT.print("Received Command: [");
        SERIAL_OUT.print(cmdbuf);
        SERIAL_OUT.println("]");
        parseCommand(cmdbuf);
        cmdbufpos = 0;  // Reset buffer
      }
    } else if (cmdbufpos < (sizeof(cmdbuf) - 1)) {
      cmdbuf[cmdbufpos++] = c;  // Add char to buffer
    } else {
      // Buffer overflow, discard command
      SERIAL_OUT.println("Error: Command too long");
      cmdbufpos = 0;  // Reset buffer
    }
  }

  // --- Periodic Status Output ---
  static auto nextStatusUpdate = nowMicros;
  const unsigned long statusUpdateInterval = 1000000;  // 1 second
  if (nowMicros >= nextStatusUpdate) {
    SERIAL_OUT.println("--- Status Update ---");
    printStatus();
    // Read and print battery voltage
    // Assuming a voltage divider: Vbat -> R1 -> ADC_PIN -> R2 -> GND
    // Voltage = ADC_reading * (AREF / ADC_resolution) * (R1 + R2) / R2
    // Example: Teensy 3.3V AREF, 10-bit ADC (1024), R1=10k, R2=10k -> Factor = 3.3/1024 * 2 = 0.006445
    const float VOLTAGE_FACTOR = 0.00967;  // Teensy 3.3V AREF, R!=2M, R2=1M -> Factor = (3.3/1024) * 3 = 0.00967
    float voltage = analogRead(PIN_VBAT) * VOLTAGE_FACTOR;
    SERIAL_OUT.print("Voltage: ");
    SERIAL_OUT.print(voltage);
    SERIAL_OUT.println(" V");
    SERIAL_OUT.println("---------------------");

    nextStatusUpdate = (nowMicros / statusUpdateInterval + 1) * statusUpdateInterval;
  }
}

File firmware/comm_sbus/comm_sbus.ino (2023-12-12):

//***********************************
// PARTS Common Robot Platform
// SBUS Test Program  				 
//***********************************

// Include necessary libraries
#include <Arduino.h> // Main Arduino library
#include <sbus.h> // Library for handling SBUS communication

// Initialize SBUS receiver on Serial4 with inversion enabled (due to SBUS standard)
bfs::SbusRx sbus_rx(&Serial4, true); 
bfs::SbusData data; // Variable to store SBUS data
bool newSbusPacket = false;     // Flag for new SBUS packet arrival
unsigned long lastLogTime = 0;
const unsigned long logInterval = 500; // 500 ms for 2 Hz logging
int setspeed[2];  //Array for holding speed values

// Constants for motor control
const int MAX_PWM = 200; // Maximum PWM value for motor speed, range 0-255

// Define pin assignments for various robot components
const int PIN_XD_EN = 2; // Pin for XD enable
const int PIN_RD_PWM1 = 3; // Right drive motor, PWM pin 1
const int PIN_LD_PWM1 = 4; // Left drive motor, PWM pin 1
const int PIN_RD_PWM2 = 5; // Right drive motor, PWM pin 2
const int PIN_LD_PWM2 = 6; // Left drive motor, PWM pin 2
const int PIN_VBAT = 14; // Battery voltage monitoring pin
const int PIN_LD_OCM = 20; // Left drive overcurrent monitor pin
const int PIN_RD_OCM = 21; // Right drive overcurrent monitor pin

// Arrays for motor control
const int motorDir[2] = {1, -1}; // Motor direction (1 for forward, -1 for reverse)
int motorPWMPin1[2] = {PIN_RD_PWM1, PIN_LD_PWM1}; // PWM pins for each motor
int motorPWMPin2[2] = {PIN_RD_PWM2, PIN_LD_PWM2}; // Secondary PWM pins for each motor

// Function to stop the motors
void stopMotors() {
    for (int i = 0; i < 2; i++) {
        analogWrite(motorPWMPin1[i], 0);
        analogWrite(motorPWMPin2[i], 0);
    }
}
// Setup function - initializes the robot's components
void setup() {
    // Initialize Serial communication for debugging
    Serial.begin(9600); // Start serial communication at 9600 bits per second
    Serial.println("Setup complete. Robot initializing...");

    // Configure motor driver pins as outputs
    pinMode(PIN_XD_EN, OUTPUT);
    pinMode(PIN_RD_PWM1, OUTPUT);
    pinMode(PIN_LD_PWM1, OUTPUT);
    pinMode(PIN_RD_PWM2, OUTPUT);
    pinMode(PIN_LD_PWM2, OUTPUT);

    // Initialize motors to off state
    digitalWrite(PIN_XD_EN, HIGH);
    analogWrite(PIN_RD_PWM1,0);
    analogWrite(PIN_RD_PWM2,0);
    analogWrite(PIN_LD_PWM1,0);
    analogWrite(PIN_LD_PWM2,0);

    // Start SBUS communication
    sbus_rx.Begin();
}

void loop() {
   // Check if new SBUS data is available
   if (sbus_rx.Read()) {
        // Update SBUS data from the receiver
        data = sbus_rx.data(); 
        // Set flag to indicate new data has been received
        newSbusPacket = true;  

        // Check if the SBUS receiver is in failsafe mode
        if (data.failsafe) {
            // If in failsafe mode, stop all motors for safety
            stopMotors(); 
            // Log to the serial monitor that failsafe mode is activated
            Serial.println("SBUS entered failsafe mode.");
            // Exit the loop early to avoid executing further commands
            return;
        }

        // Convert the SBUS channel values to motor speeds
        // 'map' scales the SBUS channel range to the motor speed range
        int linear = map(data.ch[1], 172, 1810, -MAX_PWM, MAX_PWM); // Channel 2 for linear speed
        int angular = map(data.ch[0], 172, 1810, -MAX_PWM, MAX_PWM); // Channel 1 for angular speed

        // Calculate differential motor speeds for turning
        setspeed[0] = constrain(linear - angular, -MAX_PWM, MAX_PWM);  // Motor 0 speed
        setspeed[1] = constrain(linear + angular, -MAX_PWM, MAX_PWM);  // Motor 1 speed

        // Apply the calculated motor speeds
        for (int i = 0; i < 2; i++) {
            // Control the direction and speed of each motor
            if (setspeed[i] * motorDir[i] >= 0) {
                analogWrite(motorPWMPin1[i], setspeed[i] * motorDir[i]);
                analogWrite(motorPWMPin2[i], 0);
            } else {
                analogWrite(motorPWMPin1[i], 0);
                analogWrite(motorPWMPin2[i], -setspeed[i] * motorDir[i]);
            }
        }
    } 

    // Check if a new SBUS packet flag is set
    if (newSbusPacket) {
        // Log data at a limited rate of 2Hz
        if (millis() - lastLogTime >= logInterval) {
            // Log the values of the first two SBUS channels
            Serial.print("SBUS Channel 1: ");
            Serial.print(data.ch[0]);
            Serial.print(", Channel 2: ");
            Serial.println(data.ch[1]);

            // Log the calculated speeds for both motors
            Serial.print("Motor 0 Speed: ");
            Serial.print(setspeed[0]);
            Serial.print(", Motor 1 Speed: ");
            Serial.println(setspeed[1]);

            // Reset the new SBUS packet flag after processing
            newSbusPacket = false;
            // Update the last logging time
            lastLogTime = millis();
        }
    }
}

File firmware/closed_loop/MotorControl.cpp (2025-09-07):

#include "MotorControl.h"
#include "setup.h"

void MotorControl::applyPWM(int pwmValue) {
  pwmValue = constrain(pwmValue, -255, 255);
  if (pwmValue >= 0) {
    analogWrite(ciPwmA, pwmValue);
    analogWrite(ciPwmB, 0);
  } else {
    analogWrite(ciPwmA, 0);
    analogWrite(ciPwmB, -pwmValue);
  }
}

MotorControl::MotorControl(int pinCurrent, int pinEncA, int pinEncB,
                           int pinPwmA, int pinPwmB, const char *label)
    : ciPinCurrent(pinCurrent), ciPinEncA(pinEncA), ciPinEncB(pinEncB),
      ciPwmA(pinPwmA), ciPwmB(pinPwmB), label(label) {
  resetCounter(); // Initialize state in constructor via reset
  msgcnt = 0;
  prevCounterForSpeed =
      0; // Initialized by resetCounter if called after member init
  prevTimeForSpeed = micros(); // Initialized by resetCounter
}

int32_t MotorControl::getCounter() const {
  int32_t tempCounter;
  noInterrupts();
  tempCounter = counter;
  interrupts();
  return tempCounter;
}

float MotorControl::getSpeed() const { return lastSpeed; }

float MotorControl::getTargetSpeed() const { return targetSpeed; }

void MotorControl::setTargetSpeed(float speed) {
  speed = constrain(speed, -MotorControl::MAX_SPEED, MotorControl::MAX_SPEED);

  if (targetSpeed != speed) {
    targetSpeed = speed;
    // Consider PID reset strategy carefully (e.g., only on sign change or zero
    // crossing) pid.reset(); // Resetting integrator on any change can be jerky

#if PRINT_MOVES
    SERIAL_OUT.print(label);
    SERIAL_OUT.print(" New speed target: ");
    SERIAL_OUT.println(speed);
#endif
  }
}

void MotorControl::resetCounter() {
  noInterrupts();
  counter = 0;
  lastEncTime = micros();
  // Initialize lastEnc based on current pin readings.
  lastEnc = (digitalRead(ciPinEncA) ? 2 : 0) | (digitalRead(ciPinEncB) ? 1 : 0);
  // Reset speed calculation variables
  prevCounterForSpeed = counter; // After counter itself is reset
  interrupts();

  // These are not shared with ISRs, so can be set outside critical section
  lastSpeed = 0;
  targetSpeed = 0;
  mpwm = 0;
  pid.reset();
  prevTimeForSpeed =
      lastEncTime; // Align with lastEncTime from critical section
}

void MotorControl::readCurrent() {
  float lastCurrent = 0.0;
  int ocm = analogRead(ciPinCurrent);

  float current = ocm * CURRENT_SCALE; // convert to amps.

  if (current > 0.1 || lastCurrent > 0.1) { // Threshold to reduce noise print
#if PRINT_MOVES > 1 // Make current printing higher verbosity
    SERIAL_OUT.print(label);
    SERIAL_OUT.print(" motor current: ");
    SERIAL_OUT.print(current * 1000);
    SERIAL_OUT.println(" mA");
#endif
    if (current > MAX_CURRENT) { // Uses private constant
      SERIAL_OUT.print("!!! OVER CURRENT on ");
      SERIAL_OUT.print(label);
      SERIAL_OUT.print(": ");
      SERIAL_OUT.print(current);
      SERIAL_OUT.println(" A !!!");
      // Consider a more robust safety stop, maybe disable motors via enable
      // pin?
      setTargetSpeed(0);
      mpwm = 0;    // Force PID output to zero
      applyPWM(0); // Force PWM off immediately
    }
  }
  lastCurrent = current;
}

void MotorControl::motionUpdate() {
  uint32_t currentTime = micros();

  int32_t currentCounter;
  uint32_t currentLastEncTime;

  noInterrupts(); // Protect reads of volatile variables shared with ISRs
  currentCounter = counter;         // Copy volatile counter
  currentLastEncTime = lastEncTime; // Copy volatile time
  interrupts();
  // Calculate speed based on counts over the motionUpdate interval
  float dtSpeedCalc = (currentTime - prevTimeForSpeed) * 1e-6f; // in seconds
  int32_t deltaCount = currentCounter - prevCounterForSpeed;

  if (dtSpeedCalc > 1e-6f) { // Avoid division by zero or tiny dt
    lastSpeed =
        (static_cast<float>(deltaCount) * METERS_PER_COUNT) / dtSpeedCalc;
  } else if (currentCounter == prevCounterForSpeed) {
    // If no time passed for robust calculation AND no counts,
    // rely on the timeout below to force zero if truly stopped.
  }

  // Robust zero-speed detection:
  // If counter hasn't changed since last motionUpdate AND >50ms since *any*
  // edge.
  if ((currentCounter == prevCounterForSpeed) &&
      (currentTime - currentLastEncTime > 50000)) {
    lastSpeed = 0.0f;
  }

  // Update history for the next speed calculation cycle
  prevCounterForSpeed = currentCounter;
  prevTimeForSpeed = currentTime;

  float err = targetSpeed - lastSpeed;
  mpwm = pid.update(err); // Get PID adjustment
  mpwm = constrain(mpwm, -1.0, 1.0);

  // Convert PID output (-1.0 to 1.0) to PWM value (-255 to 255)
  int setspeed = static_cast<int>(mpwm * 255.0f);

  // Stop motor if target speed is effectively zero
  if (abs(targetSpeed) < 1e-3) {
    mpwm = 0;
    setspeed = 0;
    pid.reset(); // Reset PID when stopped
  }

  applyPWM(setspeed);

  // Debug output
  if (msgcnt++ > 100 &&
      abs(setspeed) > 0) { // Only print if moving and periodically
#if PRINT_MOVES
    char message[100]; // Smaller buffer
    snprintf(message, sizeof(message),
             "%c: Tgt=%.2f Cur=%.2f Err=%.2f PIDOut=%.2f PWM=%d", label,
             targetSpeed, lastSpeed, err, mpwm, setspeed);
    SERIAL_OUT.println(message);
#endif
    msgcnt = 0;
  }
}

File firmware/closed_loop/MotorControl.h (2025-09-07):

#ifndef MOTOR_CONTROL_H
#define MOTOR_CONTROL_H

#include "PidControl.h"
#include <Arduino.h>

// Forward declaration of external pin constants
extern const int PIN_LD_OCM;

class MotorControl {
public: // Made public for ISR access, ensure volatile
  volatile uint32_t lastEncTime;
  volatile int8_t lastEnc; // Stores the last combined A/B state (0,1,2,3)
  volatile int32_t counter;

  float lastSpeed;
  float targetSpeed;
  float mpwm; // Internal PID output state

  int32_t prevCounterForSpeed; // Store counter from previous motionUpdate
  uint32_t prevTimeForSpeed;   // Store time from previous motionUpdate

  const int ciPinCurrent;
  const int ciPinEncA;
  const int ciPinEncB;
  const int ciPwmA;
  const int ciPwmB;
  const char *label;

  int msgcnt;

  // Constants used only internally
  static constexpr float CURRENT_SCALE = 0.0064f;
  static constexpr float MAX_CURRENT = 3.0f;
  static constexpr float MAX_ACCELERATION = 2.0f; // m/s^2 (Currently unused)

  void applyPWM(int pwmValue);

public: // Public interface and constants
  // --- Public Constants ---
  static constexpr float COUNTS_PER_REV = 1440.0f;
  static constexpr float WHEEL_DIAMETER = 0.070f; // meters
  static constexpr float METERS_PER_COUNT =
      (M_PI * WHEEL_DIAMETER) / COUNTS_PER_REV;
  static constexpr float MAX_SPEED = 2.0f; // m/s

  // --- Public Member Objects ---
  PidControl pid;

  // --- Constructor ---
  MotorControl(int pinCurrent, int pinEncA, int pinEncB, int pinPwmA,
               int pinPwmB, const char *label);
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

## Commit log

2020-04-29 Roll back to KiCAD v5.1.2 and add project specific libraries
    [romi_board.kicad_pcb, romi_board.sch]
2020-05-02 Add BOM
    [BOM.csv]
2020-05-02 Add teensy symbol library
2020-05-03 Add footprints for breakout boards
2020-05-03 Initial version of schematics and boards.
    [romi_board.sch, romi_board_left.kicad_pcb, romi_board_left.sch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]
2020-05-04 Create simplified footprint for teensy
2020-05-04 flip the left motor encorder connector the right way round.
    [romi_board.kicad_pcb, romi_board_left.kicad_pcb]
2020-06-09 Redesign to use two boards instead of 3
    [romi_board.sch, romi_board_bottom.kicad_pcb, romi_board_bottom.sch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]
2020-06-26 Added switches, optional USB power connector, changed out mouting holes, a few reroutes for SI
    [romi_board.kicad_pcb, romi_board.sch, romi_board_bottom.kicad_pcb]
2020-06-28 Update BOM
    [BOM.csv]
2020-07-11 Cosmetic schematic changes and added PDF's of the boards and schematics.
    [romi_board.sch]
2020-08-01 Add resistor values to schematic
    [romi_board.sch]
2020-08-01 Add interactive BOM
2020-09-28 Add assembly notes in readme for romi hardware desing
2020-09-29 add Raspberry Pi mounting instructions
2021-01-12 add encoder-only test add PJRC Encoder library test improve basic_test - use both wheels - improve integrator in PID - add conditionals to turn on/off features - improve motor ramp to ramp both forwa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
    [basic_test.ino, encoder_lib_test.ino, encoder_test.ino]
2021-09-05 Initial revision, as fabbed 20210823
    [power_control.kicad_pcb, power_control.sch]
2021-09-05 cosmetic changes: net names and component values
    [power_control.kicad_pcb, power_control.sch]
2021-09-05 folder rename
    [power_control.kicad_pcb, power_control.sch]
2021-09-05 add firmware and software for power_control board
2021-09-05 Fix power/ground terminal swap.
    [romi_board_bottom.kicad_pcb, romi_board_bottom.sch]
2021-09-05 simple closed loop motor control test code
2021-09-05 substantial rewrite of closed loop motor test code
2022-12-01 Add modified platform.txt file for teensy micro_ros library
2022-12-16 Fixed motor control loop for twist messages
    [closed_loop.ino]
2022-12-27 Fix angular velocity calculation
    [closed_loop.ino]
2023-01-07 Added schematic PDF and BOM.
    [power_control_bom.csv]
2023-02-07 Fix PID constants to be equal (left and right). Improve uros agent connectivity
    [closed_loop.ino]
2023-11-02 Update MOSFET choice in BOM.csv
    [BOM.csv]
2023-11-05 Update IMU link in BOM.csv
    [BOM.csv]
2023-11-05 Update links in BOM.csv
    [BOM.csv]
2023-11-05 Update prices in BOM.csv
    [BOM.csv]
2023-11-30 added 3d print for imu
    [Common_Robotics_IMU_Support.stl]
2023-11-30 added 3d printing doc template
2023-12-16 ultrasonic sensor first commit
2025-02-25 Corrected last checkin code
    [closed_loop.ino]
2025-02-26 Fix compile for non ROS case
    [closed_loop.ino]
2025-04-25 Improve PID class (WIP)
2025-05-03 1. Change application of PID factor to directly control motor speed instead of integrating it 2. Improve code organization with respect to ROS/Standalone conditional compilation 3. Improve variable e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
2025-05-13 Change motor encoder handling to use interupts to count pulses. Tune up PID parameters to actually achieve target speed. Additional code cleanups.
2025-08-29 Add power header and filter capacitors to bottom. Add filter capacitors to top.
    [romi_board.kicad_pcb, romi_board.kicad_sch, romi_board_bottom.kicad_pcb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]
